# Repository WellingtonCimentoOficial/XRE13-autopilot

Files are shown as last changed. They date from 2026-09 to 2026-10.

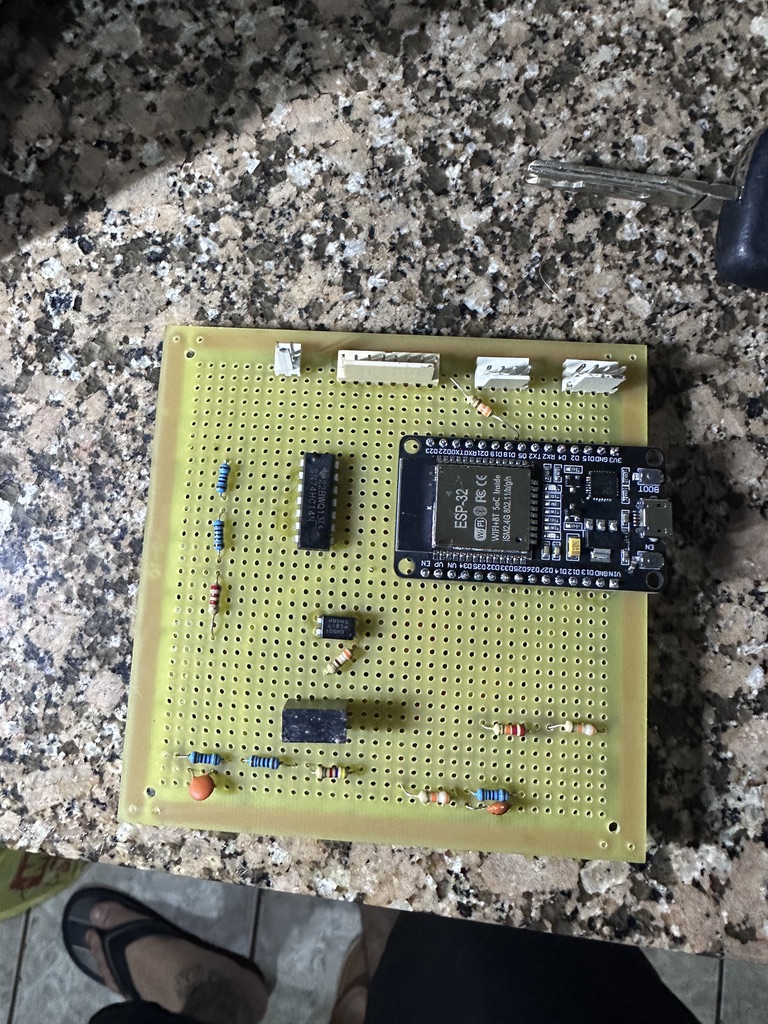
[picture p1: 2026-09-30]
designs/images/DFE2BE38-1186-41CC-8F96-BC59C99E8229_1_105_c.jpeg

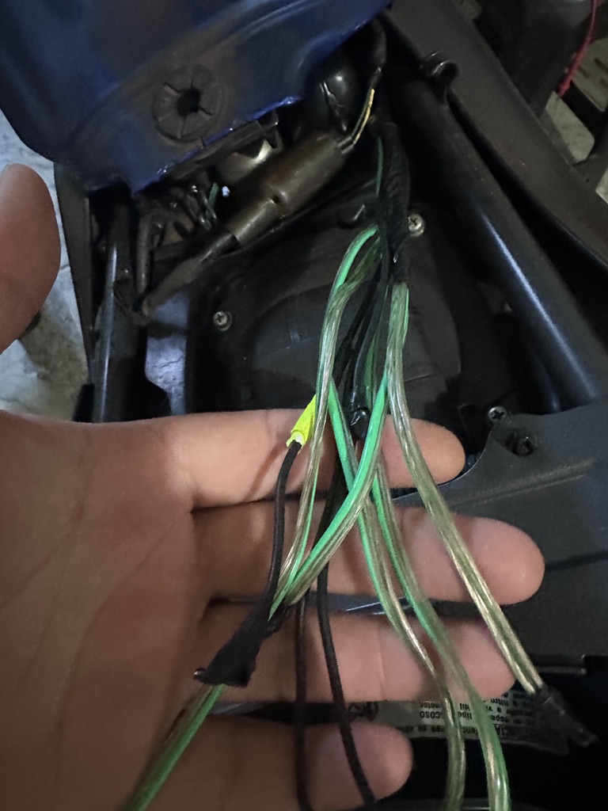
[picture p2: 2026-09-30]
designs/images/C52439D9-13C0-4BE4-ACDD-ED321F2252E7_1_105_c.jpeg

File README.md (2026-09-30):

# 🏍️ Autopilot — Circuito de Controle

Circuito baseado em **ESP32** para leitura dos sinais da XRE 300 2013 e controle do sistema de acionamento do motor.

O circuito possui:

- Condicionamento para os sinais digitais de **velocidade**, **freio** e **embreagem**
- Leitura analógica do **acelerador**
- Isolamento do **botão** através de **B05005S-1W + PC817**
- **Display OLED**
- **LED de status**
- Controle **PWM** do driver do motor (**BTS7960**)
- Alimentação por conversor **LM2596** (12 V → 5 V)

---

## 📑 Índice

- [Visão geral](#-visão-geral)
- [Entradas](#-entradas)
  - [Velocidade](#️-velocidade)
  - [Freio](#-freio)
  - [Acelerador](#️-acelerador)
  - [Embreagem](#-embreagem)
- [Resumo das tensões](#-resumo-das-tensões)
- [74HC14](#-74hc14)
- [Botão](#-botão)
- [Display OLED](#-display-oled)
- [LED de status](#-led-de-status)
- [Driver do motor](#️-driver-do-motor)
- [Pinout completo do ESP32](#-pinout-completo-do-esp32)
- [Alimentação](#-alimentação)
- [Componentes principais](#-componentes-principais)
- [Resumo das conexões](#-resumo-das-conexões)

---

## 🔌 Visão geral

O circuito é dividido nos seguintes blocos:

- 🏍️ Leitura de velocidade
- 🛑 Leitura do freio
- 🎚️ Leitura do acelerador
- 🦾 Leitura da embreagem
- 🔘 Botão com isolamento óptico
- 📺 Display OLED
- 💡 LED de indicação
- ⚙️ Controle do driver do motor
- 🔄 Condicionamento de sinais através do 74HC14
- 🔋 Alimentação com LM2596 (12 V → 5 V)

---

## 📡 Entradas

> ℹ️ As tensões de entrada abaixo são **aproximadas**. As tensões no pino foram **calculadas** a partir dos resistores do divisor: `Vpino = Ventrada × R_baixo ÷ (R_cima + R_baixo)`.

### 🏍️ Velocidade

O sinal de velocidade passa por um circuito de condicionamento antes de entrar no 74HC14.

**Ligações**

```text
Sinal de velocidade
        │
       R1
      10K
        │
        ├──────────> 1A — 74HC14
        │
       R2
       1K
        │
       R3
      2,2K
        │
       GND
```

**Componentes**

| Componente | Valor  |
|---|---|
| R1 | 10 KΩ  |
| R2 | 1 KΩ |
| R3 | 2,2 KΩ |

**Tensões**

| Ponto | Tensão |
|---|---|
| Entrada (sinal da moto)  | ~12 V |
| No pino 1A do 74HC14 | ~2,9 V |
| Saída 1Y (vai ao ESP32)  | 0 V ou 3,3 V |

A saída **1Y** do 74HC14 é conectada ao **GPIO 25** do ESP32.

---

### 🛑 Freio

O sinal de freio é condicionado através de resistor e capacitor antes de entrar no 74HC14.

**Ligações**

```text
Sinal de freio
      │
     R1
    39K
      │
      ├──────────> 2A — 74HC14
      │
     100nF
      │
     R2
    10K
      │
     GND
```

**Componentes**

| Componente | Valor  |
|---|---|
| R1 | 39 KΩ  |
| R2 | 10 KΩ  |
| C1 | 100 nF |

**Tensões**

| Ponto | Tensão |
|---|---|
| Entrada (sinal da moto)  | ~12 V |
| No pino 2A do 74HC14 | ~2,45 V |
| Saída 2Y (vai ao ESP32)  | 0 V ou 3,3 V |

A saída **2Y** do 74HC14 é conectada ao **GPIO 4**.

---

### 🎚️ Acelerador

O acelerador possui leitura analógica, portanto o sinal é conectado ao **GPIO 32** do ESP32, que possui entrada ADC.

> ⚠️ O sinal **não** passa pelo 74HC14.

**Ligações**

```text
Sinal do acelerador
        │
       R1
      20K
        │
        ├──────────> GPIO 32 (ADC)
        │
       R2
      39K
        │
       GND
```

**Componentes**

| Componente | Valor |
|---|---|
| R1 | 20 KΩ |
| R2 | 39 KΩ |

**Tensões**

| Ponto | Tensão |
|---|---|
| Entrada (sinal da moto)  | ~5 V |
| No GPIO 32 (ADC) | ~3,3 V (no máximo) |

O GPIO 32 é utilizado como entrada analógica para realizar a leitura da tensão do acelerador.

> ⚠️ Com 5 V na entrada, o divisor entrega cerca de 3,3 V, que é o limite do ESP32. Se o sensor passar de 5 V, a leitura pode saturar.

---

### 🦾 Embreagem

O sinal da embreagem passa por um circuito de condicionamento antes de entrar no 74HC14.

**Ligações**

```text
Sinal da embreagem
        │
       R1
      4,7K
        │
        ├──────────> 4A — 74HC14
        │
       R2
       1K
        │
      100nF
        │
       R3
       10K
        │
       GND
```

**Componentes**

| Componente | Valor  |
|---|---|
| R1 | 4,7 KΩ |
| R2 | 1 KΩ |
| R3 | 10 KΩ  |
| C1 | 100 nF |

**Tensões**

| Ponto | Tensão |
|---|---|
| Entrada (sinal da moto)  | 4,7 V |
| No pino 4A do 74HC14 | 3,3 V |
| Saída 4Y (vai ao ESP32)  | 0 V ou 3,3 V |

A saída **4Y** do 74HC14 é conectada ao **GPIO 19**.

> ℹ️ Com 4,7 V na entrada, o divisor entrega cerca de 3,3 V no pino 4A, igual à alimentação do 74HC14.

---

## 🔋 Resumo das tensões

| Sinal | Entrada (aprox.) | No pino (calculado) | Saída do 74HC14 / destino |
|---|---|---|---|
| Velocidade | ~12 V | ~2,9 V | 0 V ou 3,3 V → GPIO 25 |
| Freio | ~12 V | ~2,45 V | 0 V ou 3,3 V → GPIO 4 |
| Acelerador | ~5 V | ~3,3 V | direto no GPIO 32 (ADC) |
| Embreagem  | 4,7 V | 3,3 V | 0 V ou 3,3 V → GPIO 19 |

O 74HC14 **inverte** o sinal:

- Sinal alto na entrada → saída em **0 V**
- Sinal baixo na entrada → saída em **3,3 V**

---

## 🔄 74HC14

O 74HC14 é utilizado para **condicionamento e inversão** dos sinais digitais de velocidade, freio e embreagem.

**Alimentação**

```text
VCC (pino 14) → 3.3V
GND (pino 7)  → GND
```

**Capacitor de desacoplamento**

Um capacitor de **100 nF** é ligado entre o **VCC (pino 14)** e o **GND (pino 7)**, o mais **próximo possível do CI**, para filtrar ruídos da alimentação.

```text
3.3V ────┬──────── VCC (pino 14)
         │
       100nF
         │
GND ─────┴──────── GND (pino 7)
```

**Pinout utilizado**

| 74HC14 | Pino | Função | ESP32 |
|---|---|---|---|
| 1A | 1 | Entrada velocidade | — |
| 1Y | 2 | Saída velocidade | GPIO 25 |
| 2A | 3 | Entrada freio | — |
| 2Y | 4 | Saída freio | GPIO 4  |
| 4Y | 8 | Saída embreagem | GPIO 19 |
| 4A | 9 | Entrada embreagem  | — |
| VCC | 14 | Alimentação | 3.3V |
| GND | 7 | Alimentação | GND |

---

## 🔘 Botão

O botão utiliza isolamento óptico através do conjunto **B05005S-1W** e **PC817**.

**B05005S-1W**

| Pino | Conexão |
|---|---|
| 1 | GND |
| 2 | 5V |
| 3 | Cátodo do PC817  |
| 4 | Botão |

**PC817**

```text
Anodo
  │
 R 1K
  │
Botão

Coletor → GPIO 18
Emissor → GND
```

O PC817 fornece isolamento entre o circuito do botão e a entrada do ESP32.

---

## 📺 Display OLED

O display OLED utiliza comunicação **I²C**.

| OLED | ESP32 |
|---|---|
| GND  | GND |
| VDD  | 3.3V |
| SCK  | GPIO 22 |
| SDA  | GPIO 21 |

**Pinout I²C**

```text
SCK → GPIO 22
SDA → GPIO 21
```

---

## 💡 LED de status

O LED é acionado diretamente pelo **GPIO 5** através de um resistor limitador de corrente.

```text
GPIO 5
  │
220Ω
  │
Anodo do LED
  │
LED
  │
Catodo
  │
GND
```

**Componentes**

| Componente | Valor |
|---|---|
| Resistor | 220 Ω |

---

## ⚙️ Driver do motor

O ESP32 controla o sentido e o acionamento do motor através do driver **BTS7960**, com sinais **PWM**.

**Motor utilizado:** JGY370, 12 V, 10 RPM.

### Sinais e alimentação da lógica

| Driver | Conexão |
|---|---|
| GND | GND |
| VCC | 5V (saída do LM2596) |
| R_EN | 5V (saída do LM2596) |
| L_EN | 5V (saída do LM2596) |
| RPWM | GPIO 27 |
| LPWM | GPIO 26 |

> ℹ️ Os pinos **R_EN** e **L_EN** precisam estar em nível alto para o driver funcionar. Ligados ao 5V, ficam sempre habilitados.

**Sinais PWM**

```text
GPIO 27 → RPWM
GPIO 26 → LPWM
```

Os dois GPIOs são utilizados para controle PWM do driver.

### Borne de potência

| Borne | Conexão |
|---|---|
| B- | GND da moto |
| B+ | 12V pós-chave (o mesmo que alimenta o LM2596) |
| M+ | Motor JGY370 |
| M- | Motor JGY370 |

```text
12V pós-chave ──┬──> LM2596 (entrada)
                └──> B+  (BTS7960)

GND da moto ─────────> B-  (BTS7960)

M+ ──────────> Motor JGY370
M- ──────────> Motor JGY370
```

---

## 📌 Pinout completo do ESP32

| GPIO | Função | Tipo |
|---|---|---|
| GPIO 4  | Freio | Digital |
| GPIO 5  | LED | Saída |
| GPIO 18 | Botão | Digital |
| GPIO 19 | Embreagem  | Digital |
| GPIO 21 | OLED SDA | I²C |
| GPIO 22 | OLED SCK | I²C |
| GPIO 25 | Velocidade | Digital |
| GPIO 26 | Motor LPWM | PWM |
| GPIO 27 | Motor RPWM | PWM |
| GPIO 32 | Acelerador | ADC |

---

## 🔋 Alimentação

A alimentação do circuito vem da moto, através de um conversor **LM2596**:

- **Entrada:** 12V pós-chave da moto
- **Saída:** 5V

```text
12V pós-chave ──> LM2596 ──> 5V ──┬──> ESP32 (VIN)
                                  ├──> BTS7960 (VCC, R_EN, L_EN)
                                  └──> B05005S-1W (pino 2)

GND da moto ──> LM2596 (GND) ─────┬──> ESP32 (GND)
                                  └──> BTS7960 (GND)

GND da moto ──> BTS7960 (borne B-)
```

O ESP32 é alimentado pelos pinos **VIN** e **GND**.

> ℹ️ O GND da moto entra no **LM2596**, e o ESP32 já fica ligado ao GND por ele. Não é preciso puxar outro fio de GND da moto até o ESP32.

O circuito utiliza três tensões:

| Tensão | Utilização |
|---|---|
| 12V pós-chave | Entrada do LM2596 e borne B+ do BTS7960 (motor) |
| 5V | ESP32 (VIN), BTS7960 (VCC, R_EN, L_EN) e B05005S-1W |
| 3.3V | Lógica do ESP32, 74HC14 e OLED |
| GND | Referência comum do circuito (GND da moto, levado ao ESP32 pelo LM2596) |

> ⚠️ **Importante:** o sinal do acelerador é uma entrada analógica e deve permanecer conectado ao GPIO 32, sem passar pelo 74HC14.

---

## 🧩 Componentes principais

- ESP32
- 74HC14
- B05005S-1W
- PC817
- Display OLED I²C
- Driver de motor BTS7960
- Motor JGY370 12 V 10 RPM
- Conversor LM2596 (12 V → 5 V)
- LED
- Resistores
- Capacitores de 100 nF

---

## 📋 Resumo das conexões

| Sistema | GPIO / Conexão  |
|---|---|
| Velocidade | GPIO 25 |
| Freio | GPIO 4 |
| Acelerador | GPIO 32 — ADC |
| Embreagem  | GPIO 19 |
| Botão | GPIO 18 |
| LED | GPIO 5 |
| OLED SDA | GPIO 21 |
| OLED SCK | GPIO 22 |
| Motor RPWM | GPIO 27 |
| Motor LPWM | GPIO 26 |

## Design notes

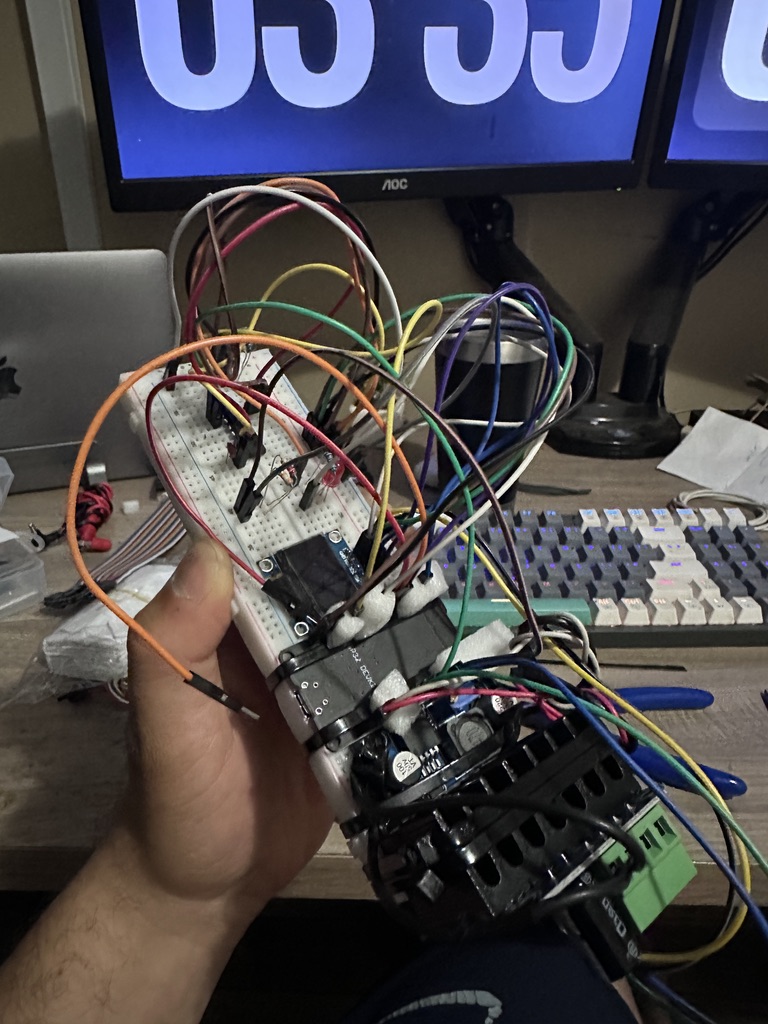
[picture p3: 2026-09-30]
designs/images/C554EF11-0711-4BB9-858C-B46FD143EA21_1_105_c.jpeg

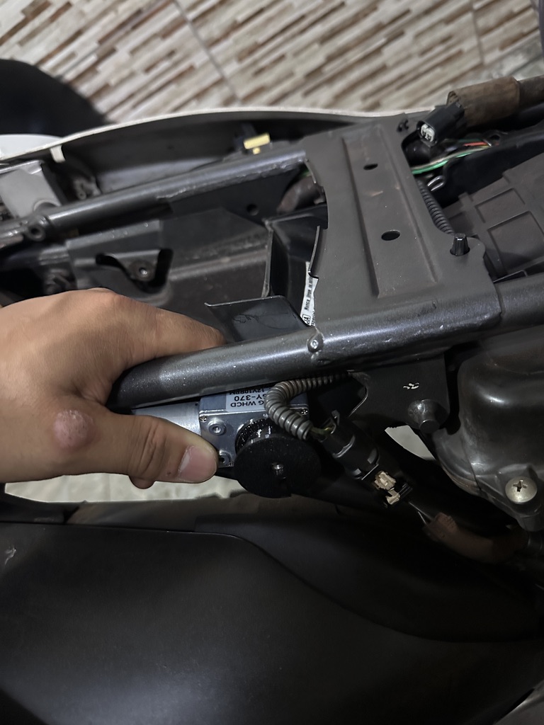
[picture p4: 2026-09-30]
designs/images/47B07C3D-93E7-4E30-BF45-8BC7A5BDA783_1_105_c.jpeg

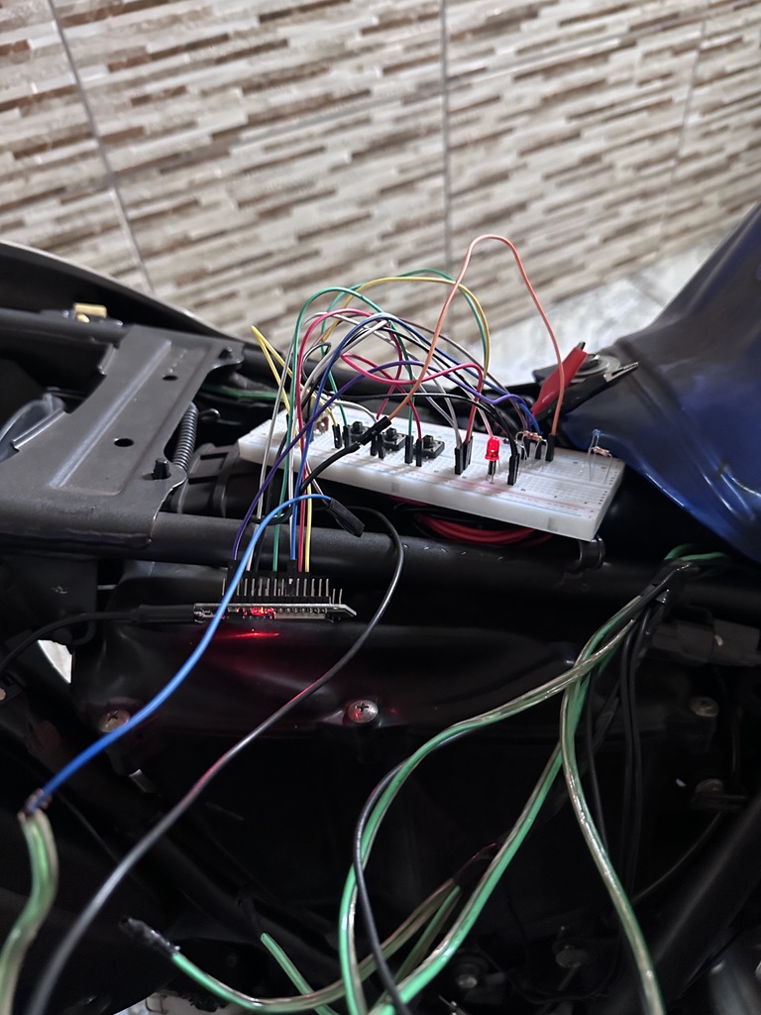
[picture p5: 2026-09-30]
designs/images/57D2694C-8C6E-4DEC-9E69-24CDD6BCA9E5_1_105_c.jpeg

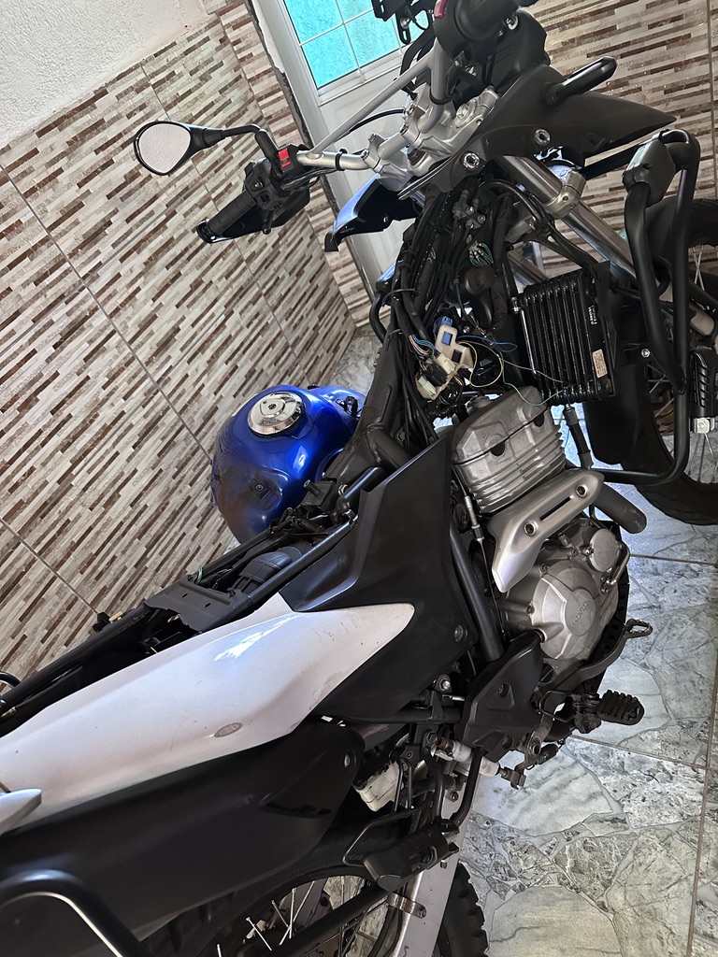
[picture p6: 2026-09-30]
designs/images/879AB9FC-0341-45B4-9EE7-9393C5C2F372_1_105_c.jpeg

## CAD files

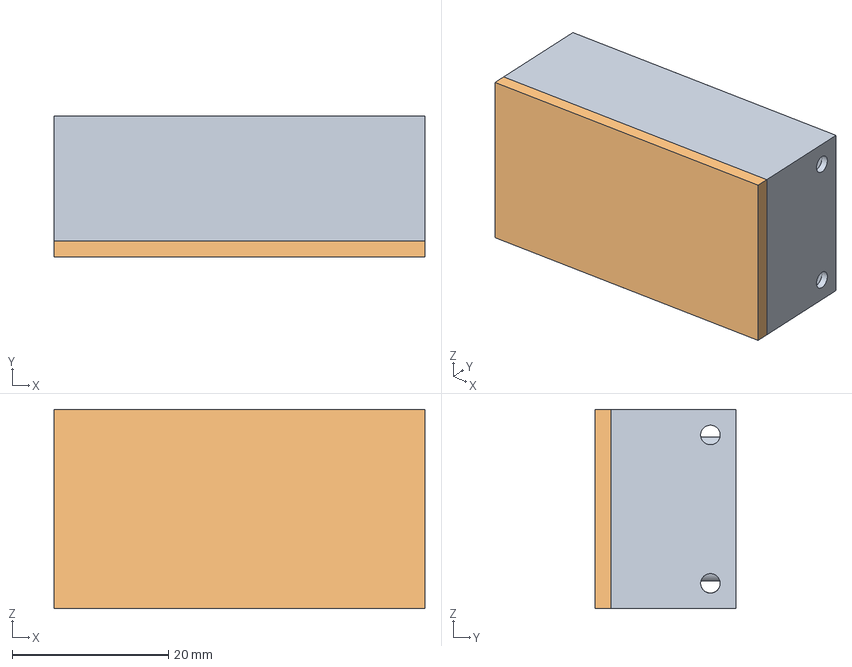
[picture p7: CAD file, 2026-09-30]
designs/3d/lm2596.FCStd
47.5 x 18.0 x 25.5 mm
case (Solid)
tampa (Solid)

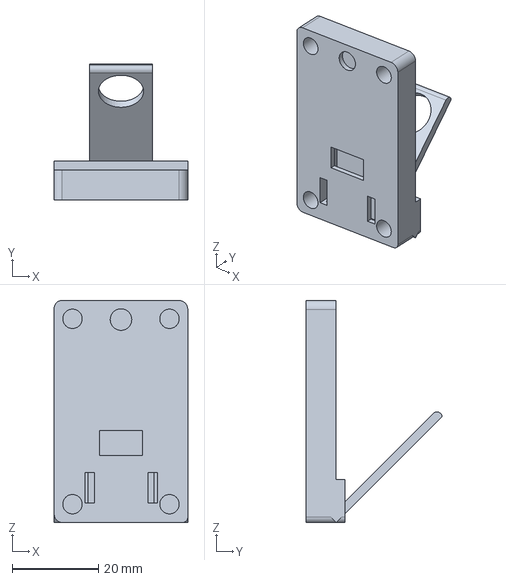
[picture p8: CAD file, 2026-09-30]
designs/3d/button.FCStd
31.0 x 31.5 x 51.5 mm

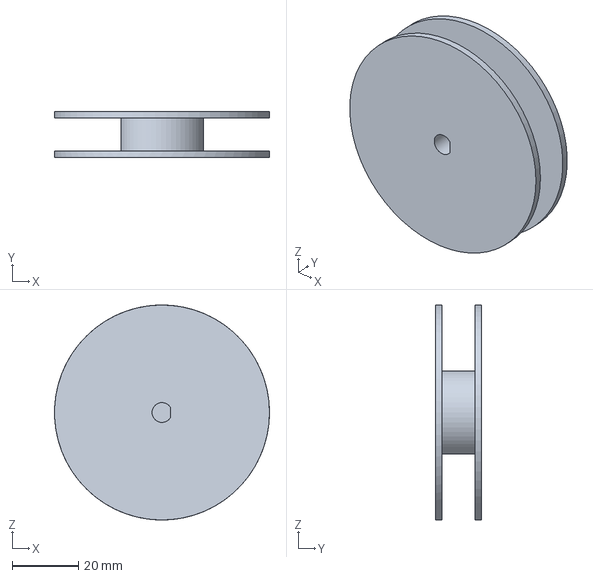
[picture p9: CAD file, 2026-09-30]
designs/3d/polia.FCStd
65.0 x 14.0 x 65.0 mm

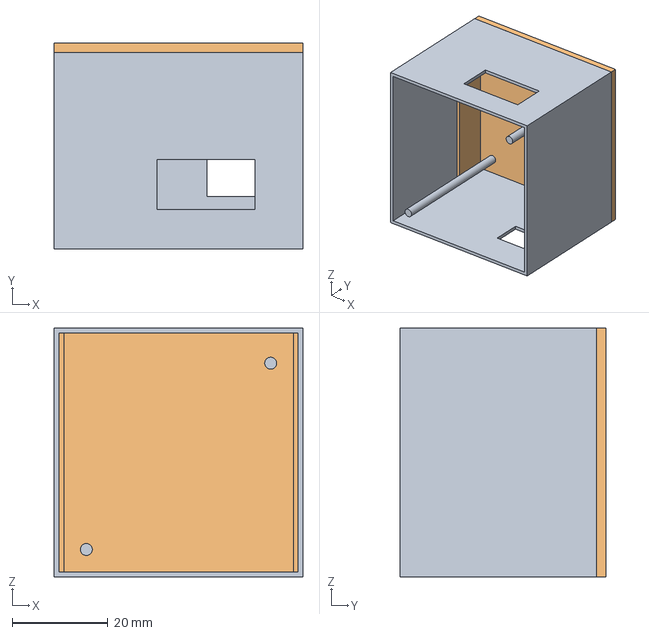
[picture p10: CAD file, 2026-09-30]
designs/3d/bts7960.FCStd
52.0 x 43.0 x 52.0 mm
case (Solid)
tampa (Solid)

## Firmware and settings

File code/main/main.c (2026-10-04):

#include <stdio.h>
#include "gpio_hall.h"
#include "cruise_control.h"
#include "motor_control.h"
#include "tps_sensor.h"
#include "speed_sensor.h"
#include "clutch_sensor.h"
#include "brake_sensor.h"
#include "control_button.h"
#include "driver/gpio.h"
#include "oled.h"
#include "led.h"
#include "adc_hall.h"
#include "esp_adc/adc_oneshot.h"
#include "ble.h"

void app_main(void)
{
    gpio_install_isr_service(0);

    adc_oneshot_unit_handle_t adc_handle = adc_init();

    control_button_init();
    brake_sensor_init();
    clutch_sensor_init();
    tps_sensor_init(adc_handle);
    motor_init();
    led_init();
    oled_init();
    speed_sensor_init();
    cruise_control_init();
    ble_init();
}

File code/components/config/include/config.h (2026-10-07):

#pragma once

#include "esp_adc/adc_oneshot.h" 
#include "driver/ledc.h"
#include "driver/i2c_master.h"

// THROTTLE CONFIGURATIONS
#define ACCELERATOR_SENSOR_CHANNEL ADC_CHANNEL_4 //GPIO 32
#define ACCELERATOR_SENSOR_ATTEN ADC_ATTEN_DB_12
#define ACCELERATOR_MINIMUM_TOLERANCE 0.99f
#define ACCELERATOR_MINIMUM_VOLTAGE 0.31f
#define ACCELERATOR_MAXIMUM_VOLTAGE 2.75f
#define ACCELERATOR_MAXIMUM_TOLERANCE 99.0f

// MOTOR CONFIGURATIONS
#define MOTOR_ACCELERATION_PWM_GPIO 27
#define MOTOR_ACCELERATION_PWM_CHANNEL LEDC_CHANNEL_0
#define MOTOR_DECELERATION_PWM_GPIO 26
#define MOTOR_DECELERATION_PWM_CHANNEL LEDC_CHANNEL_1

// SPEED SENSOR CONFIGURATIONS
#define SPEED_SENSOR_GPIO 25
#define SPEED_SENSOR_WHEEL_CIRCUMFERENCE_METERS 2.184f
#define SPEED_SENSOR_PULSES_PER_WHEEL_TURN 8.0f
#define SPEED_SENSOR_CALIBRATION_FACTOR 1.05f
#define SPEED_SENSOR_FILTER_ALPHA 0.15f
#define SPEED_SENSOR_MAX_SPEED_KMH 150.0f

// BRAKE SENSOR CONFIGURATIONS
#define BRAKE_SENSOR_GPIO 4
#define BRAKE_SENSOR_DEBOUNCE_TIME 50

// CLUTCH SENSOR CONFIGURATIONS
#define CLUTCH_SENSOR_GPIO 19
#define CLUCH_SENSOR_DEBOUNCE_TIME 50

//BTN CONTROL CONFIGURATIONS
#define BTN_CONTROL_GPIO 18
#define BTN_CONTROL_DEBOUNCE_TIME 180

// PID CONFIGURATIONS
#define PID_KP 0.0f
#define PID_KI 0.0f
#define PID_KD 0.0f

// DISPLAY OLED CONFIGURATIONS
#define I2C_MASTER_SCL_GPIO         22
#define I2C_MASTER_SDA_GPIO         21
#define I2C_MASTER_NUM              I2C_NUM_0                   /*!< I2C port number for master dev */
#define I2C_MASTER_FREQ_HZ          100000                      /*!< I2C master clock frequency */
#define I2C_MASTER_ADDRESS          0x3C

// OTHER CONFIGURATIONS 
#define LED_GPIO 5
#define MINIMUM_SPEED_LIMIT 60.0f

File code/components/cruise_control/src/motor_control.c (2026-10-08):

#include "motor_control.h"
#include "freertos/FreeRTOS.h"
#include "freertos/task.h"
#include "esp_log.h"
#include <stdint.h>
#include "pwm_hall.h"
#include "config.h"
#include <math.h>
#include "tps_sensor.h"
#include "led.h"

void motor_open_throttle(float duty){
    pwm_set_duty(MOTOR_DECELERATION_PWM_CHANNEL, 0);

    pwm_set_duty(MOTOR_ACCELERATION_PWM_CHANNEL, duty);
    ESP_LOGI(__func__, "Acceleration PWM set. Current duty: %.2f.", duty);
}
void motor_close_throttle(float duty){
    pwm_set_duty(MOTOR_ACCELERATION_PWM_CHANNEL, 0);

    pwm_set_duty(MOTOR_DECELERATION_PWM_CHANNEL, duty);
    ESP_LOGI(__func__, "Deceleration PWM set. Current duty: %.2f.", duty);
}

void motor_stop(void){
    motor_open_throttle(0);
    motor_close_throttle(0);
    ESP_LOGI(__func__, "Accelerate duty and decelerate duty set to 0.");
}

float limit_pwm(float pid_output){
    uint32_t pwm_limit = (1 << PWM_DUTY_RESOULTION) - 1;

    pid_output = fabsf(pid_output);

    if(pid_output > pwm_limit){
        return pwm_limit;
    }

    return pid_output;
}

void motor_return_throttle_to_idle(void){
    motor_stop();
    
    if(!tps_is_throttle_at_idle()){
        ESP_LOGI(__func__, "Throttle is not at idle (current: %.2f%%). Resetting position...", tps_get_throttle_position());
        
        float last_correct_throttle_position = tps_get_throttle_position();
        uint32_t last_correct_throttle_position_time = xTaskGetTickCount();
        
        while(1){
            while(!tps_is_throttle_at_idle()){
                motor_close_throttle(255);
    
                if(last_correct_throttle_position < tps_get_throttle_position()){
                    motor_stop();
    
                    while(last_correct_throttle_position < tps_get_throttle_position()){
                        vTaskDelay(pdMS_TO_TICKS(10));
                        continue;
                    }
    
                    last_correct_throttle_position_time = xTaskGetTickCount();
    
                    while((xTaskGetTickCount() - last_correct_throttle_position_time) < pdMS_TO_TICKS(500)){
                        vTaskDelay(pdMS_TO_TICKS(10));
                        continue;
                    }
    
                    last_correct_throttle_position = tps_get_throttle_position();
                }
    
                ESP_LOGI(__func__, "Resetting throttle: current position %.2f%% -> target 0%%.", tps_get_throttle_position());
                vTaskDelay(pdMS_TO_TICKS(10));
            }

            vTaskDelay(pdMS_TO_TICKS(500));

            if(tps_is_throttle_at_idle()){
                break;
            }
        }

        vTaskDelay(pdMS_TO_TICKS(300));
        
        motor_stop();

        ESP_LOGI(__func__, "Throttle successfully reset to 0%%.\n");
    }
}

void motor_set_throttle_to_max(void){ // to test
    if(!tps_is_throttle_at_max()){
        ESP_LOGI(__func__, "Throttle is not in max (current: %.2f%%). setting max position...", tps_get_throttle_position());
        motor_open_throttle(255);
        while(!tps_is_throttle_at_max()){
            ESP_LOGI(__func__, "Setting throttle: current position %.2f%% -> target 100%%.", tps_get_throttle_position());
            vTaskDelay(pdMS_TO_TICKS(10));
        }
        motor_stop();
        ESP_LOGI(__func__, "Throttle successfully set to 100%%.\n");
    }
}

void motor_calibrate(void){
    motor_set_throttle_to_max();
    motor_return_throttle_to_idle();
}

void motor_set_throttle(float throttle_position){ 
    ESP_LOGI(__func__, "Waiting for throttle to be released...");
    led_set_blink_now(true, 50);
    
    while(!tps_is_throttle_at_idle()){
        vTaskDelay(pdMS_TO_TICKS(10));
    }
    ESP_LOGI(__func__, "Throttle released.");
    
    if(tps_get_throttle_position() < throttle_position){
        ESP_LOGI(__func__, "Setting throttle to %.2f%%...", throttle_position);
        led_set_blink_now(true, 200);

        motor_open_throttle(255);
        while(tps_get_throttle_position() < throttle_position){
            vTaskDelay(pdMS_TO_TICKS(10));
        }
        motor_stop();
        ESP_LOGI(__func__, "Throttle successfully set to %.2f%%.\n", throttle_position);
    }

    led_set_blink_now(false, 200);
}


void motor_set_output(float pid_output){
    float duty = limit_pwm(pid_output);

    if(pid_output > 0.0f && !tps_is_throttle_at_max()){
        motor_open_throttle(duty);
    }else if(pid_output < 0.0f && !tps_is_throttle_at_idle()){
        motor_close_throttle(duty);
    }else{
        motor_stop();
    }
}

void motor_init(){
    pwm_init(MOTOR_ACCELERATION_PWM_GPIO, MOTOR_ACCELERATION_PWM_CHANNEL);
    pwm_init(MOTOR_DECELERATION_PWM_GPIO, MOTOR_DECELERATION_PWM_CHANNEL);

    ESP_LOGI(__func__, "Motor initialized successfully.");
}

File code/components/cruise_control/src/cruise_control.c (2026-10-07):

#include "cruise_control.h"
#include "config.h"
#include "gpio_hall.h"
#include "freertos/FreeRTOS.h"
#include "freertos/task.h"
#include "esp_log.h"
#include <stdbool.h>
#include "speed_sensor.h"
#include "tps_sensor.h"
#include "motor_control.h"
#include <stdint.h>
#include "pid.h"
#include "brake_sensor.h"
#include "clutch_sensor.h"
#include "control_button.h"
#include "led.h"
#include "esp_timer.h"
#include "oled.h"

static float speed_target = 0;
static bool is_ready = false;
static bool is_active = false;

TaskHandle_t pilot_task_handle;
TaskHandle_t calibration_task_handle;

TaskHandle_t get_pilot_task_handle(void){
    return pilot_task_handle;
}

TaskHandle_t get_calibration_task_handle(void){
    return calibration_task_handle;
}

void calibration_task(void *pvParameter){
    while(1){
        xTaskNotifyWait(0, UINT32_MAX, NULL, portMAX_DELAY);

        if(get_current_speed() != 0.0f || is_active){
            continue;
        }

        if(!control_button_confirmed_press(5000)){
            oled_show_error(OLED_ERROR_BUTTON_NOT_CONFIRMED);
            continue;
        }

        led_set_blink_now(true, 50);

        oled_show_motor_calibrating(true);
        motor_calibrate();
        oled_show_motor_calibrating(false);

        led_set_blink_now(false, 50);

        while(control_button_is_pressed()){
            vTaskDelay(pdMS_TO_TICKS(10));
        }

        while(ulTaskNotifyTake(pdTRUE, 0) > 0){
            ESP_LOGW(__func__, "Discarded spurious button trigger during hold.\n");
        }
    }
}

void pilot_task(void *pvParameter){
    while(1){
        xTaskNotifyWait(0, UINT32_MAX, NULL, portMAX_DELAY);

        float current_speed = get_current_speed();
        float current_throttle_position = tps_get_throttle_position();

        if(!is_ready){
            oled_show_error(OLED_ERROR_NOT_READY);
            continue;
        }

        if(!control_button_confirmed_press(1000)){
            oled_show_error(OLED_ERROR_BUTTON_NOT_CONFIRMED);
            continue;
        }
        
        if(brake_sensor_is_pressed()){
            oled_show_error(OLED_ERROR_BRAKE_ACTIVE);
            ESP_LOGI(__func__, "Auto pilot not enabled because the brake is pressed.\n");
            
            continue;
        }
        
        // if(clutch_is_actuated()){
            //     oled_show_error(OLED_ERROR_CLUTCH_ACTIVE);
            //     ESP_LOGI(__func__, "Auto pilot not enabled because the clutch is actuated.\n");
            //     continue;
            // }
            
            if(current_speed < MINIMUM_SPEED_LIMIT){
            oled_show_error(OLED_ERROR_SPEED_TOO_LOW);
            ESP_LOGI(__func__, "Auto pilot not enabled because the speed is below %d km/h.\n", MINIMUM_SPEED_LIMIT);
            
            continue;
        }

        if(!auto_pilot_is_active()){
            enable_auto_pilot(current_speed, current_throttle_position);
        }else{
            disable_auto_pilot();
        }

        while(control_button_is_pressed()){
            vTaskDelay(pdMS_TO_TICKS(10));
        }

        while(ulTaskNotifyTake(pdTRUE, 0) > 0){
            ESP_LOGW(__func__, "Discarded spurious button trigger during hold.\n");
        }
    }
}

void cruise_control_task(void *pvParameter){
    int64_t previous_time = esp_timer_get_time();

    while(1){
        int64_t current_time = esp_timer_get_time();
        float elapsed_time_s = (current_time - previous_time) / 1000000.0f;

        previous_time = current_time;

        if(auto_pilot_is_active()){
            float current_speed = get_current_speed();
            float acceleration_error = speed_target - current_speed;
            float pid_output = pid_calculate(acceleration_error, elapsed_time_s);

            motor_set_output(pid_output);
        }
        vTaskDelay(pdMS_TO_TICKS(10));
    }
}

void enable_auto_pilot(float speed, float throttle_position){
    motor_set_throttle(throttle_position);
    
    speed_target = speed;
    is_active = true;
    
    led_turn_on();
    
    ESP_LOGI(__func__, "Speed target set to %.0f km/h.", speed);
    ESP_LOGI(__func__, "Auto pilot enabled.\n");
}

void disable_auto_pilot(){
    is_active = false;
    speed_target = 0;
    is_ready = false;

    reset_pid();
    motor_return_throttle_to_idle();
    led_turn_off();

    is_ready = true;

    ESP_LOGI(__func__, "Auto pilot disabled.\n");
}

bool auto_pilot_is_active(){
    return is_active;
}

float get_speed_target(){
    return speed_target;
}

void cruise_control_init(){
    motor_return_throttle_to_idle();

    xTaskCreate(pilot_task, "pilot_task", 2048, NULL, 4, &pilot_task_handle);
    xTaskCreate(calibration_task, "calibration_task", 2048, NULL, 4, &calibration_task_handle);
    xTaskCreate(cruise_control_task, "cruise_control_task", 2048, NULL, 3, NULL);

    is_ready = true;

    ESP_LOGI(__func__, "Cruise control initialized successfully.");
}

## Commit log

2026-09-30 organize files
    [bts7960.FCStd, button.FCStd, lm2596.FCStd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]
2026-10-08 set pid kd to 20
